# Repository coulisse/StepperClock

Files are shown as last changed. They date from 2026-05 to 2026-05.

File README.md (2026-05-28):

StepperClock

<div align="center">







</div>

Questo progetto utilizza un **ESP8266** per pilotare un motore passo-passo con estrema precisione temporale, eliminando le interferenze tipiche delle funzioni bloccanti o dello stack Wi-Fi.

---

## 📝 Descrizione del Progetto
L'obiettivo è generare un segnale di STEP ogni **60 ms** esatti. Per raggiungere una precisione di livello cronometrico, il codice bypassa le funzioni standard di Arduino (come `delay()` o `digita[...]

Il motore passo-passo è collegato ad un pignone che comanda una cascata di ingranaggi, di cui tre di questi sono collegati a ore, minuti e secondi.

[Schema completo in formato DWG](docs/completo.dxf.dwg)

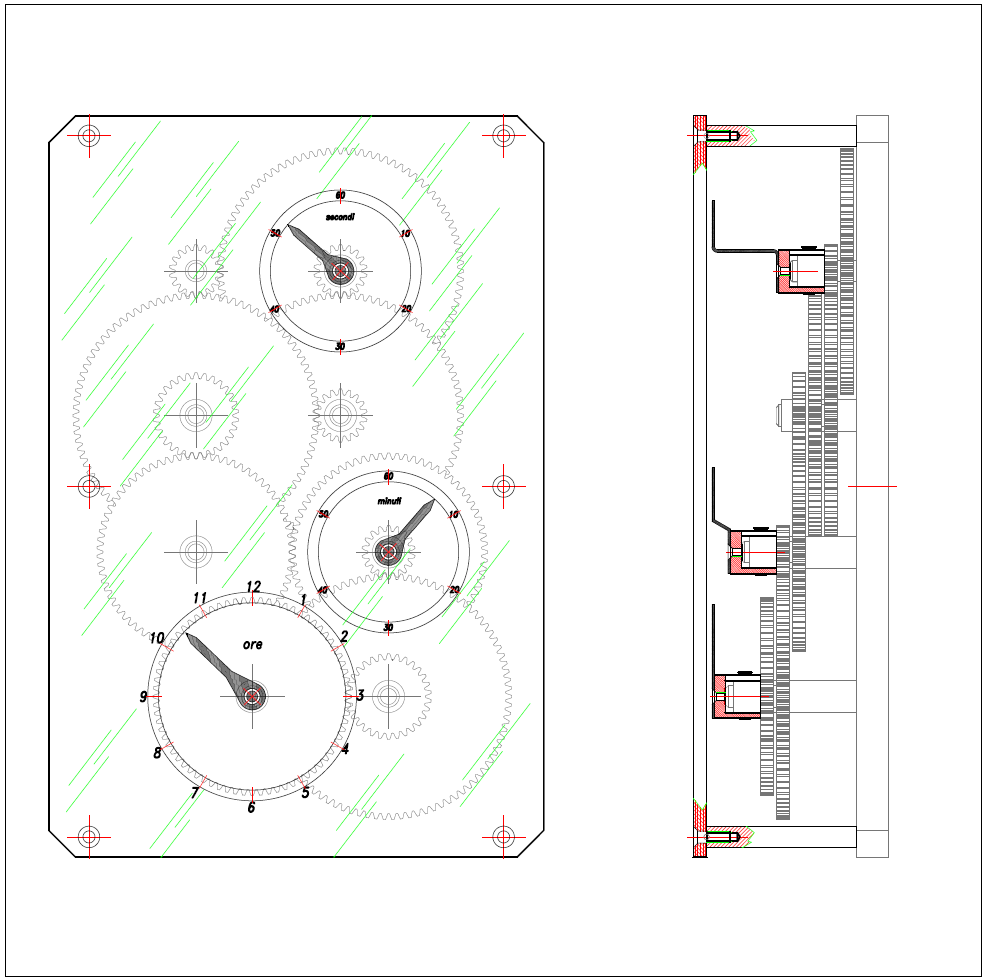
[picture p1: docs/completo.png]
Schema completo


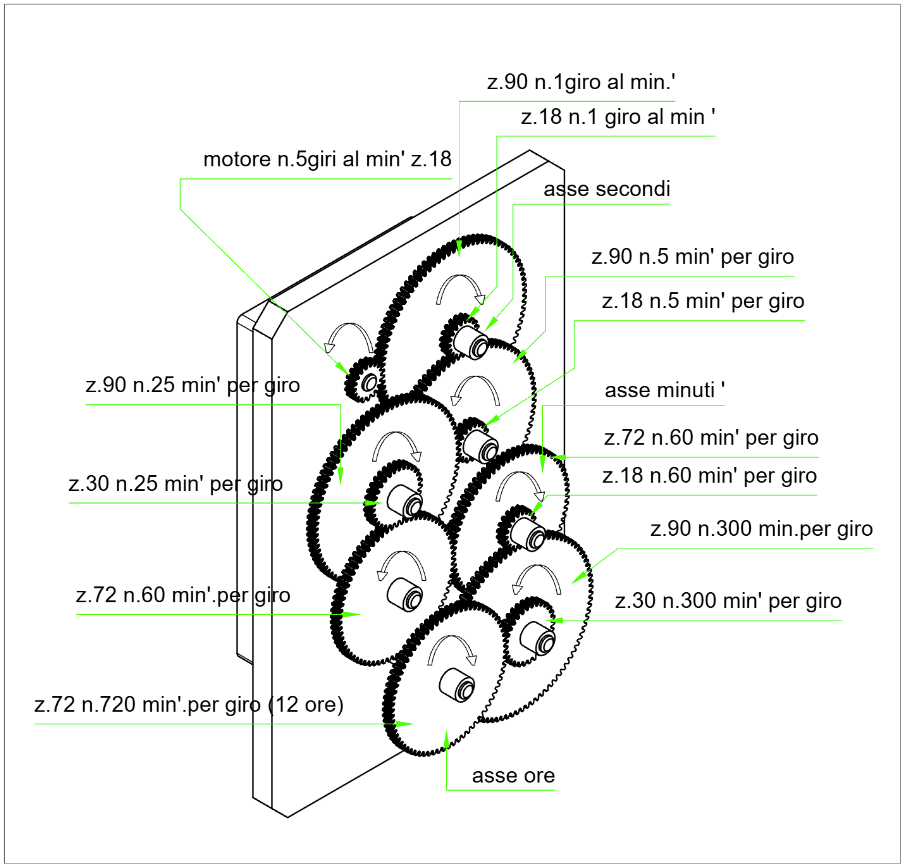
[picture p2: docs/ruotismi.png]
ruotismi


---

## 🔌 Schema di Collegamento

### Tabella dei Pin
| Componente | Pin ESP8266 | Pin Driver (A4988/DRV8825) | Funzione |
| :--- | :--- | :--- | :--- |
| **Alimentatore 12V** | - | **VMOT / GND** | Potenza Motore |
| **Alimentatore 5V** | **VIN** | **VDD** | Logica |
| **Massa Comune** | **GND** | **GND** | Riferimento 0V |
| **Segnale Step** | **GPIO 5 (D1)** | **STEP** | Impulso movimento |
| **Segnale Dir** | **GPIO 4 (D2)** | **DIR** | Direzione rotazione |

> **Nota:** Ricorda di inserire un condensatore elettrolitico (100µF) tra i pin VMOT e GND del driver per assorbire i picchi di corrente.

## 💻 Descrizione del Codice

### 1. Ottimizzazione del Sistema
Nel `setup()`, il Wi-Fi viene spento con `wifi_set_opmode(NULL_MODE)`. Questo è fondamentale: lo stack Wi-Fi dell'ESP8266 "ruba" cicli di CPU ogni pochi millisecondi, causando ritardi imprevedibi[...]

### 2. Il Timer e l'Interrupt
Il cuore è la funzione `onTimer()`, marcata con `ICACHE_RAM_ATTR` per essere eseguita direttamente dalla RAM (più veloce).
* **Calcolo Ticks:** Con un prescaler di 16 su una CPU a 80MHz, `300.000` ticks corrispondono esattamente a **60.000 µs** (60 ms).
* **ASM Nop:** Il brevissimo impulso di 3 microsecondi è generato con un ciclo `nop` (No Operation) in Assembly, garantendo che il driver riconosca lo scalino di tensione.

### 3. Loop Principale
Il `loop()` rimane vuoto, contenendo solo un `yield()` per permettere al sistema (Watchdog Timer) di respirare senza resettare la scheda, lasciando tutto il lavoro critico al Timer hardware.

---

## 🛠️ Requisiti Hardware
* Microcontrollore ESP8266 (NodeMCU o Wemos D1 Mini).
* Driver Stepper DRV8825.
* Motore Passo-Passo (NEMA 17 o simili).
* Alimentatore DC adeguato alla coppia del motore.

## 🎬 Multimedia
* [📥 Scarica Video 1 (Tasto destro -> Salva link con nome)](docs/video1.mp4)
* [📥 Scarica Video 2 (Tasto destro -> Salva link con nome)](docs/video2.mp4)

## 👥 Autori

- Samuele Gerbaldo *(project leader)*
- Marwan El Kazzari
- Jacopo Scotto
- Mattia Canepa

## 🤝 Supporto esterno

- Corrado Gerbaldo *(coding)*
- Giorgio Gerbaldo *(3D Modeling Specialist)*

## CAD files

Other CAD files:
docs/completo.dxf.dwg

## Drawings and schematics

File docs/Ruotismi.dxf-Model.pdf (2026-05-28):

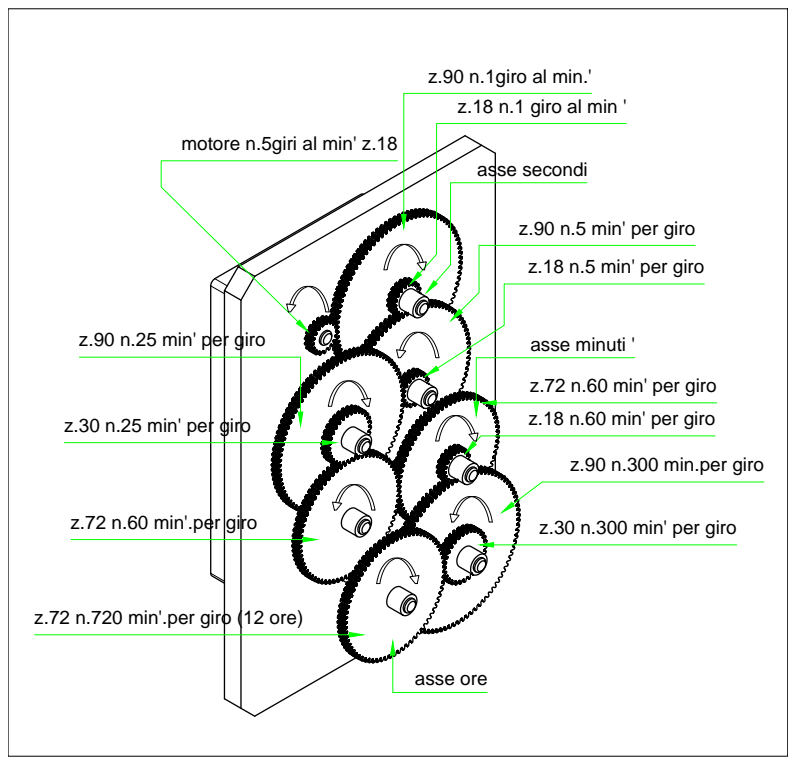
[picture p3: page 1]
z.72 n.720 min'.per giro (12 ore); asse secondi asse minuti ' asse ore

z.90 n.1giro al min.'
z.18 n.1 giro al min '

motore n.5giri al min' z.18

z.90 n.5 min' per giro

z.18 n.5 min' per giro

z.90 n.25 min' per giro

z.72 n.60 min' per giro
z.18 n.60 min' per giro

z.30 n.25 min' per giro

z.90 n.300 min.per giro

z.72 n.60 min'.per giro

z.30 n.300 min' per giro

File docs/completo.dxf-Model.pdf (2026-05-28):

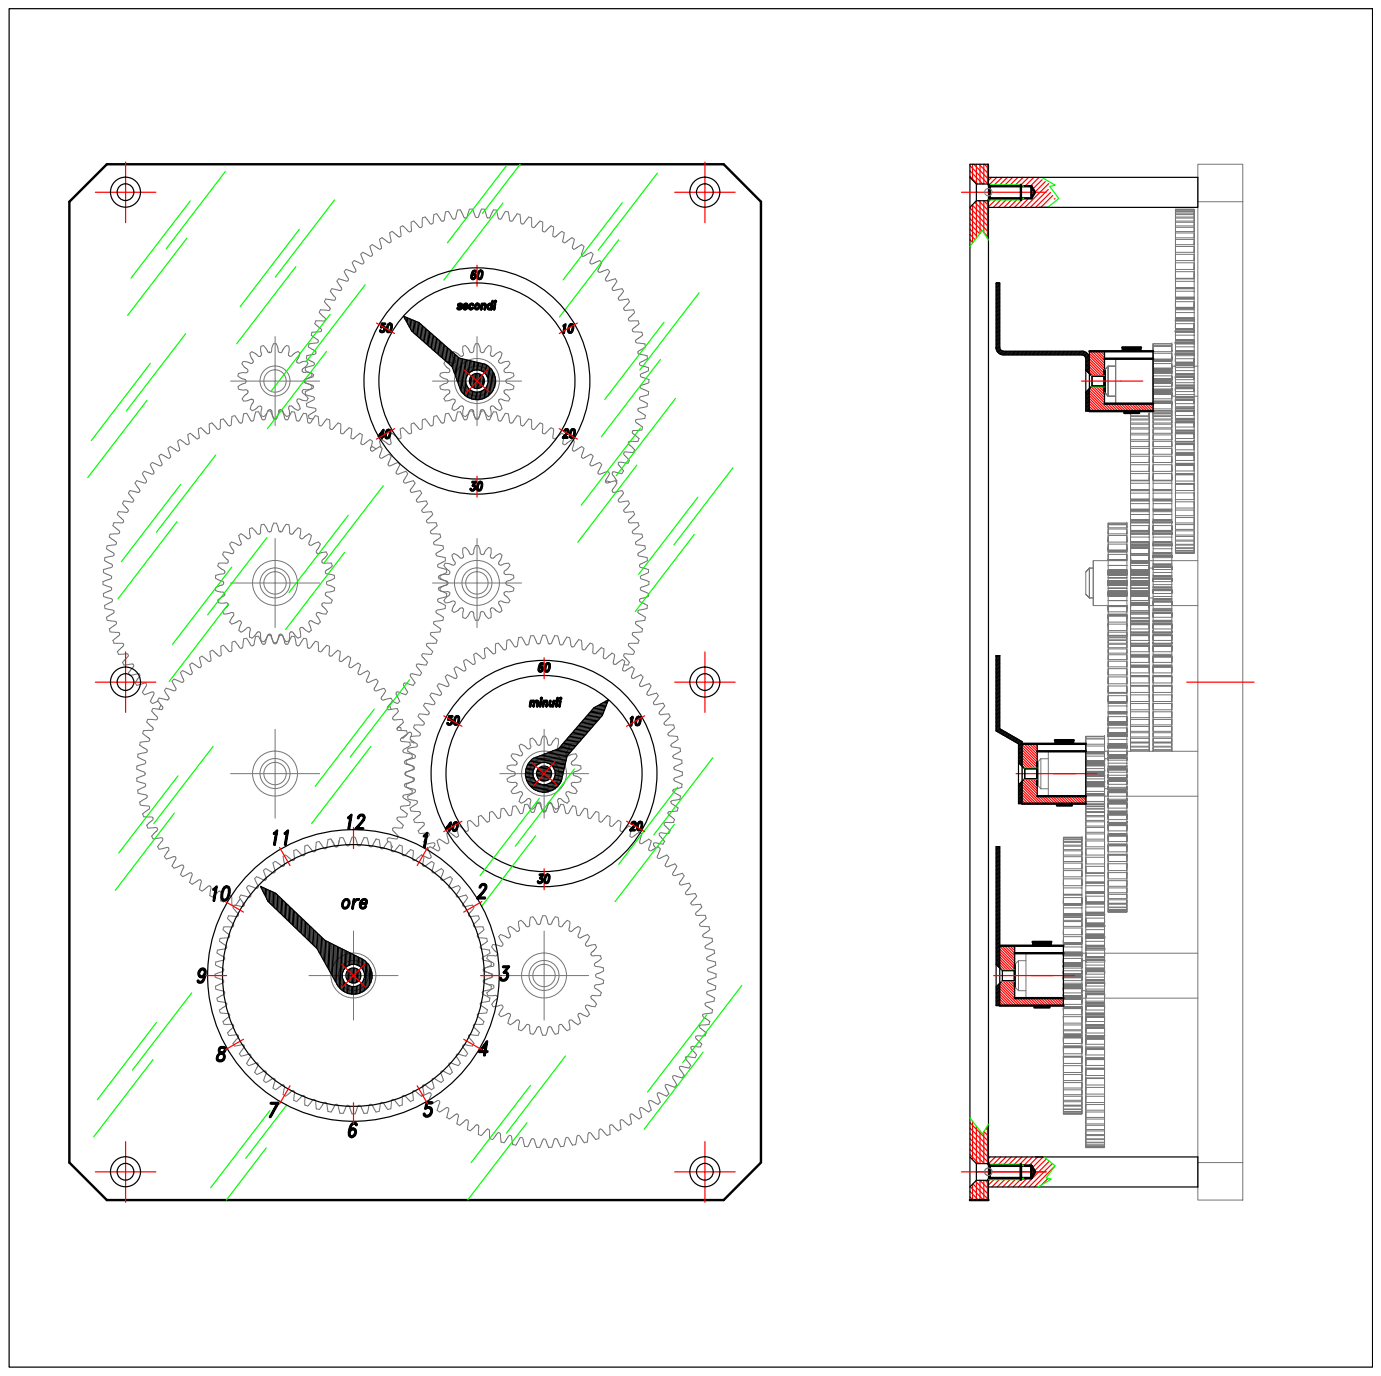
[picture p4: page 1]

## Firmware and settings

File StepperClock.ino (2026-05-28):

#include <Arduino.h>

extern "C" {
  #include "user_interface.h"
}

#define STEP_PIN 5
#define DIR_PIN 4

// 60 ms esatti con prescaler 16
#define TIMER_TICKS 300000

// Accesso diretto registri (più preciso di digitalWrite)
#define GPIO_SET  GPIO_REG_WRITE(GPIO_OUT_W1TS_ADDRESS, (1 << STEP_PIN))
#define GPIO_CLEAR GPIO_REG_WRITE(GPIO_OUT_W1TC_ADDRESS, (1 << STEP_PIN))

void ICACHE_RAM_ATTR onTimer()
{
  /* Impulso HIGH ~3 us garantiti */
  GPIO_SET;

  /* 3 us @ 80 MHz ≈ 240 cicli */
  for (volatile uint16_t i = 0; i < 240; i++) {
    __asm__ __volatile__("nop");
  }

  GPIO_CLEAR;

  /* Ricarica one-shot */
  timer1_write(TIMER_TICKS);
}

void setup()
{
  Serial.begin(9600);
  /* Disabilita WiFi completamente (riduce jitter) */
  Serial.println(F("System start...")); 
  wifi_set_opmode(NULL_MODE);
  wifi_station_disconnect();
  wifi_set_sleep_type(NONE_SLEEP_T);
  Serial.println(F("WiFi disabled")); 

  pinMode(STEP_PIN, OUTPUT);
  pinMode(DIR_PIN, OUTPUT);
  digitalWrite(STEP_PIN, LOW);
  digitalWrite(DIR_PIN, LOW); 
  Serial.println(F("output pin enabled")); 

  /* Configurazione Timer1 */
  timer1_isr_init();
  timer1_attachInterrupt(onTimer);
  timer1_enable(TIM_DIV16, TIM_EDGE, TIM_SINGLE);
  timer1_write(TIMER_TICKS);
  Serial.println(F("timer enabled")); 
  Serial.println(F("System initialized")); 
}

void loop()
{
  /* Mantiene il sistema stabile lato WDT */
  //delay(1);
  yield();
}

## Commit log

2026-02-27 Add StepperClock functionality with timer control
2026-02-27 Enhance README with project details and requirements
    Added detailed project description, features, wiring diagram, code explanation, and hardware requirements for the ESP8266 Precision Clock Stepper Control project.
2026-02-27 Integrate Mermaid wiring diagram in README
    Added wiring diagram using Mermaid syntax to README.
2026-02-27 Add tutorial link for stepper motor control
    Added a link to a tutorial for controlling stepper motors.
2026-05-28 Schema montaggio e ingranaggi
    [completo.dxf.dwg]
2026-05-28 disegni ruotismi
    [completo.dxf.dwg]
2026-05-28 cambiato senso di rotazione
2026-05-28 Enhance project description in README
    Added details about stepper motor and PDF model reference.

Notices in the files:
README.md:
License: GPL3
